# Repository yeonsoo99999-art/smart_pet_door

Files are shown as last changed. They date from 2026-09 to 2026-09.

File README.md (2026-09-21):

# Smart Pet Door — Scratch-to-Open

A cat door that opens for a *request*, not a presence. Instead of a motion or
proximity sensor, a piezo disc listens to the door panel: the cat has to
scratch at a steady rate to "ask", and a leaky-integrator gauge decides when
the request is convincing enough to lift the flap.

One stray knock never opens the door — a single tap lights one pixel of the
gauge and drains away. Only sustained scratching fills the gauge to the
target. Difficulty ("cat personality") is set purely by the decay rate, so a
harder mode asks for *faster* tapping, not harder hits.

<p align="center">
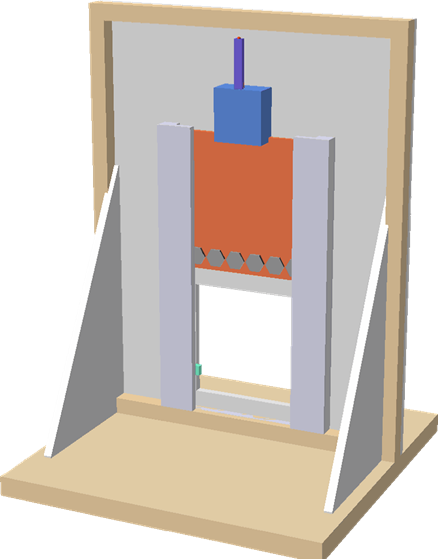
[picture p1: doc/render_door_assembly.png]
Door assembly: servo on top, flap riding in the side channels
  
  &nbsp;&nbsp;
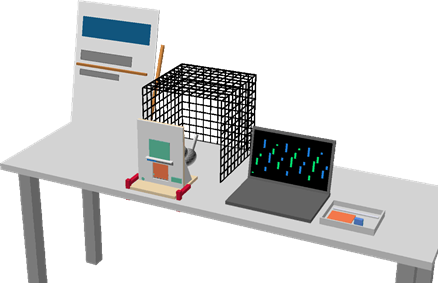
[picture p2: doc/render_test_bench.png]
Test bench: door rig, cat cage and monitoring laptop on a table
  
</p>
<p align="center"><em>Left: door assembly — the SG90 servo lifts the flap through the side channels.
Right: test bench layout with the rig, a cat enclosure and the monitoring laptop.</em></p>

## What's in this repository

| Path | Contents |
|---|---|
| `piezo_servo/` | Arduino sketch: piezo sensing, tap judging, SG90 servo flap drive, MAX7219 8×8 gauge/animations |
| `webview/` | Flask web dashboard — a live 3D digital twin (Three.js) of the door with a scratch simulator, waveform view and request log |
| `doc/` | Laser-cutting DXF files for the MDF enclosure, plus build notes |
| `run.bat` | One-click launcher for the dashboard on Windows |

## Hardware

- Arduino Uno (or compatible)
- Piezo disc → `A0` (signal), GND
- SG90 servo → `D9` (signal), external 5 V supply, common GND
- MAX7219 8×8 LED matrix → `DIN D11`, `CS D10`, `CLK D13`, 5 V, GND
- Laser-cut MDF enclosure (see `doc/README.md` for sheets, parts and assembly)

## Installation

1. **Firmware** — open `piezo_servo/piezo_servo.ino` in the Arduino IDE and
   upload it to the board (115200 baud). On boot it runs a visible self-test:
   full matrix flash, gauge fill, and a servo sweep.

2. **Dashboard** — requires Python 3.10+.

   ```
   pip install -r webview/requirements.txt
   ```

## Usage

Start the dashboard:

```
python webview/app.py --port COM3   # open the serial port at start
python webview/app.py               # or pick the port in the UI
```

Then open http://127.0.0.1:5000. On Windows, `run.bat [COM port]` installs the
dependencies if needed, starts the server and opens the browser.

**No hardware?** Press **Simulate** and drag on the acrylic pad in the 3D view —
pointer speed becomes the piezo peak, and the digital twin runs the exact same
judging logic as the firmware.

Things to try:

- **Cat personality** (Kitten / Adult / Grumpy) changes the decay: minimum tap
  rates of about 1 / 2.5 / 5 taps per second. The setting is sent to the board
  over serial, so the physical door really changes too.
- **Scratch threshold** slider separates table knocks from real scratches.
- **Test servo** sends `o` to the board for a forced open cycle.
- Every successful request is logged with time, mode and peak value
  (`webview/data/requests.csv`).

Serial protocol, difficulty math and sound credits are documented in
`webview/README.md`.

## Author

**Yeonsoo Kang**

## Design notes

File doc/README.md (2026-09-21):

# Laser-cutting DXF — Scratch-to-Open Cat Door

Foam-board prototype panels ported to MDF. Dimensions and mechanics are
unchanged; only the material thicknesses differ.

## Materials

| | Thickness | Used for | Sheet |
|---|---|---|---|
| MDF | **3 mm** | panel, base, braces, channels, servo mount | A, B (600×300) |
| MDF | **2 mm** | flap only | C (200×200) |

**Why two thicknesses.** Channel slot depth = spacer thickness.
A 3 mm spacer gives a 3 mm slot; a 3 mm flap in it has zero clearance and jams.
**A 2 mm flap leaves 1 mm of clearance.** Laser-cut edges are smooth, so 1 mm is enough.

3 mm is the standard laser-cutting thickness: a 40–60 W machine cuts it in one pass.

## Files

```
sheetA_MDF_3T.dxf    600×300 — panel, base #1, servo plate, ribs ×2, LED visor, stopper
sheetB_MDF_3T.dxf    600×300 — braces ×2, base #2, spacers ×2, covers ×2, spares
sheetC_MDF_2T.dxf    200×200 — flap ×2 (one spare)
*_2.7T.dxf           same layout re-fit for 2.7 mm stock
*_tr.dxf / _FIXED    revised nesting variants
```

## Layers

| Layer | Operation |
|---|---|
| `CUT` | cut |
| `ENGRAVE` | engrave (assembly guide lines). Optional, but they make assembly easier |
| `SHEET` | sheet outline. **Do not cut** — layout reference only |

## Parts list

| No. | Part | Qty | Thickness | Notes |
|---|---|---|---|---|
| 01 | Panel 200×260 | 1 | 3T | 70×70 opening, 3 bottom tabs |
| 02 | Base 200×200 | **2** | 3T | **glue 2 layers = 6 mm** so clamps cannot crack it |
| 03 | Brace | 2 | 3T | right triangle 90×160, 4 tabs |
| 04 | Channel spacer 180×10 | 2 | 3T | creates the slot depth |
| 05 | Channel cover 180×22 | 2 | 3T | grips 12 mm of the flap edge |
| 06 | Bottom stopper 90×8 | 1 | 3T | |
| 07 | Servo plate 60×60 | 1 | 3T | 2 slotted SG90 screw holes, Ø14 horn pass-through |
| 08 | Servo rib | 2 | 3T | 18 mm standoff |
| 09 | LED visor 116×20 | 1 | 3T | for direct sunlight outdoors |
| 10 | Flap 90×85 | 2 | **2T** | Ø3 string hole, engraved weight positions |

## Servo mount

The SG90 body does **not** pass through the plate. The flange sits on the front
face and is held by two M2 screws.

- Screw slots: ±13.9 mm from center, **8×2.8 slots** — absorbs hole-spacing
  variation between units
- Ø14 hole: clearance for the horn boss
- The two ribs stand the plate **18 mm off the panel**, so the arm clears the
  channel cover (rear face, Y=79) by 7.5 mm

## Assembly order

```
1. Glue the two base sheets together (6 mm)              cure 2 h
2. Glue channel spacers, then covers, to the panel back  align to engraved lines
3. Insert the flap and free-fall test it                 <- checkpoint
4. Add M8 nuts until the flap weighs 30–40 g (2T MDF is 11 g)
5. Fit the panel's bottom tabs into the base slots
6. Fit both braces into the panel and base slots         check squareness
7. Fit the two servo ribs into the panel slots, seat the servo plate
8. Fasten the servo with two M2 screws; connect arm and string
9. Scratch pad, LEDs, visor, sensors, wiring
```

Tabs press-fit lightly thanks to the kerf (~0.15 mm). If loose, one drop of wood glue.

## Changes from the foam-board version

| | Foam board | MDF |
|---|---|---|
| Panel | 5 mm | **3 mm** |
| Channel spacer | 5 mm | 3 mm |
| Flap | 3 mm foam, 2 g | **2 mm MDF, 11 g** |
| Slot clearance | 2 mm | **1 mm** (smooth cut edges make it enough) |
| Assembly | all glued, aligned by eye | **tab-and-slot self-alignment** |
| Base | 12 mm plywood | two 3T layers = 6 mm |
| Weights | 6–8 M8 nuts | **4 are enough** |

The heavier flap and smoother surfaces **greatly reduce the free-fall failure
risk**, and the torn string holes seen with foam board are gone.

## Cautions

- **MDF is very sensitive to water.** Once wet it swells and is permanently
  damaged. The outdoor-booth rule stands: if it rains, pick it up and retreat.
- Laser-cut edges carry soot. Wipe with a dry cloth before assembly to keep it
  off hands and clothes.
- Cutting 3 mm MDF needs ventilation. Follow your makerspace's rules.

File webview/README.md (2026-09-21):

# Scratch-to-Open · Web View

Flask dashboard that mirrors the cat door as a digital twin. It reads the
`peak,servo` stream from `piezo_servo.ino`, animates the flap, servo arm and
LED gauge, and keeps a request log.

```
pip install -r webview/requirements.txt

python webview/app.py --port COM3   # open the serial port at start
python webview/app.py               # pick the port in the UI, or simulate
```

Then open http://127.0.0.1:5000.

## Serial formats

| Sketch | Line | Handling |
|---|---|---|
| piezo_servo.ino | `peak,servo` | flap follows the reported servo angle |
| catdoor.ino | `peak gauge` | gauge taken from hardware |
| catdoor.ino | `OPEN,<mode>` | open cycle, meow |
| piezo_servo.ino | `mode,i,target,amp` | board confirming difficulty + threshold |
| catdoor.ino | `blocked` | IR beam flag |

`piezo_servo.ino` goes silent once the flap is closed, so a 180° reading older
than 150 ms is treated as closed.

## Simulation

Without hardware, press **Simulate** and drag on the scratch pad. Pointer speed
becomes the piezo peak. A single knock lights one pixel and drains; only a
sustained scratch fills the gauge. Difficulty follows the build book: the
target changes little, the per-window decay is what makes it hard.

Open events are appended to `data/requests.csv`.

## Difficulty

The cat personality sits in the top bar and drives both ends. Picking one sends
`1`, `2` or `3` to the board, which runs the same judge the twin does, so the
physical door really does change. Each tap adds a fixed amount and the gauge
decays continuously, so **what a mode asks for is tapping speed, not force**:

| Mode | Minimum rate | Comfortable rate | Taps to open |
|---|---|---|---|
| Kitten | 1.0 /s | 2 /s | 4 |
| Adult | 2.5 /s | 5 /s | 5 |
| Grumpy | 5.0 /s | 10 /s | 5 |

Below the minimum the gauge can never reach the target, so one stray knock never
opens the door. A sustained scratch hits the ~12.5 taps/s ceiling and opens any
mode. The threshold slider sends `a<n>` to the board; both settings are re-sent
whenever the board reboots, so a brown-out cannot desync the two ends.

## Sound

Each cat personality has its own meow, picked by the active difficulty:

| Mode | File | Character |
|---|---|---|
| Kitten | `meow_kitten.wav` | high soft squeak, ~1960 Hz |
| Adult | `meow_adult.wav` | a cat asking to go out, ~610 Hz |
| Grumpy | `meow_grumpy.wav` | low demanding yowl, ~245 Hz |

Sources and licences are in `static/sound/CREDITS.md`. Browsers block audio until the
page is touched, so the speaker button turns orange with a "click once" tooltip until
then; its first press only unlocks audio, later presses mute and unmute. If the files are
missing, a synthesized meow is used instead.

## Cat coats

The cat behind the door can be black, orange tabby, Siamese, mackerel tabby,
white or calico. Pick it from the selector in the twin card, or pass
`?coat=orange` in the URL. Coats are painted procedurally at load time, so no
image assets are needed.

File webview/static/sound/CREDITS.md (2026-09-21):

# Sound credits

One voice per cat personality. The difficulty mode picks the file, so the pitch
alone tells a visitor which cat they are talking to. All sources are free of
restrictions (CC0 or public domain); no attribution is required and this note
only records provenance.

| Mode | File | Length | Pitch | Source |
|---|---|---|---|---|
| Kitten | `meow_kitten.wav` | 0.81 s | ~1960 Hz, rising | *Cat Purr & Meow* by Kerzoven (`cat_softmew.wav`), CC0 — https://opengameart.org/content/cat-purr-meow |
| Adult | `meow_adult.wav` | 0.62 s | ~610 Hz, asking | *NoTrip* by Heismark, public domain — https://commons.wikimedia.org/wiki/File:NoTrip.ogg |
| Grumpy | `meow_grumpy.wav` | 0.85 s | ~245 Hz, demanding | *Meow of a Siamese cat* by freemaster2, CC0 — https://commons.wikimedia.org/wiki/File:Meow_of_a_Siamese_cat_-_freemaster2.wav |

The adult clip is cut from a recording of a cat asking to be let outside, which is
exactly what this door is about. Only the isolated cat vocalisation is used; the
human speech elsewhere in that recording is not included.

Edits: trimmed to the mew itself, DC removed, peak normalised to −1 dBFS, 5 ms
fade-in and 50 ms fade-out. Format: WAV, mono, 16-bit, 44.1 kHz.

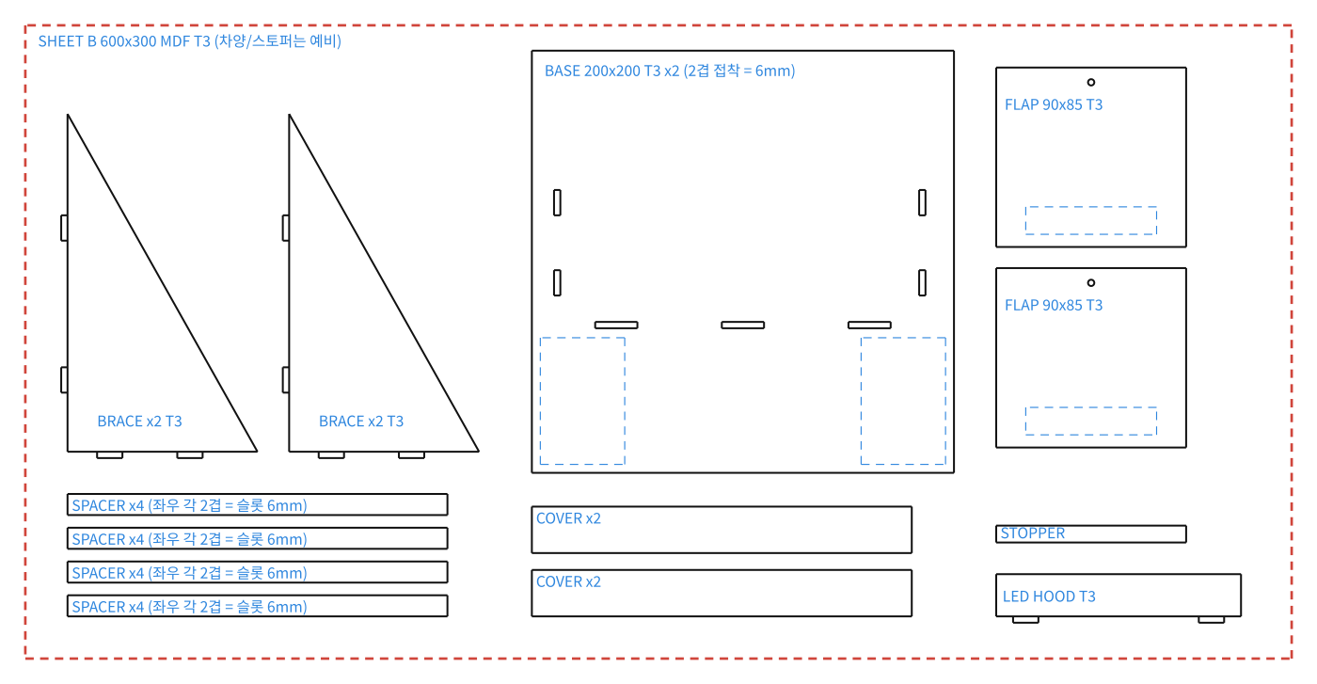
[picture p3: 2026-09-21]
doc/sheetB.png

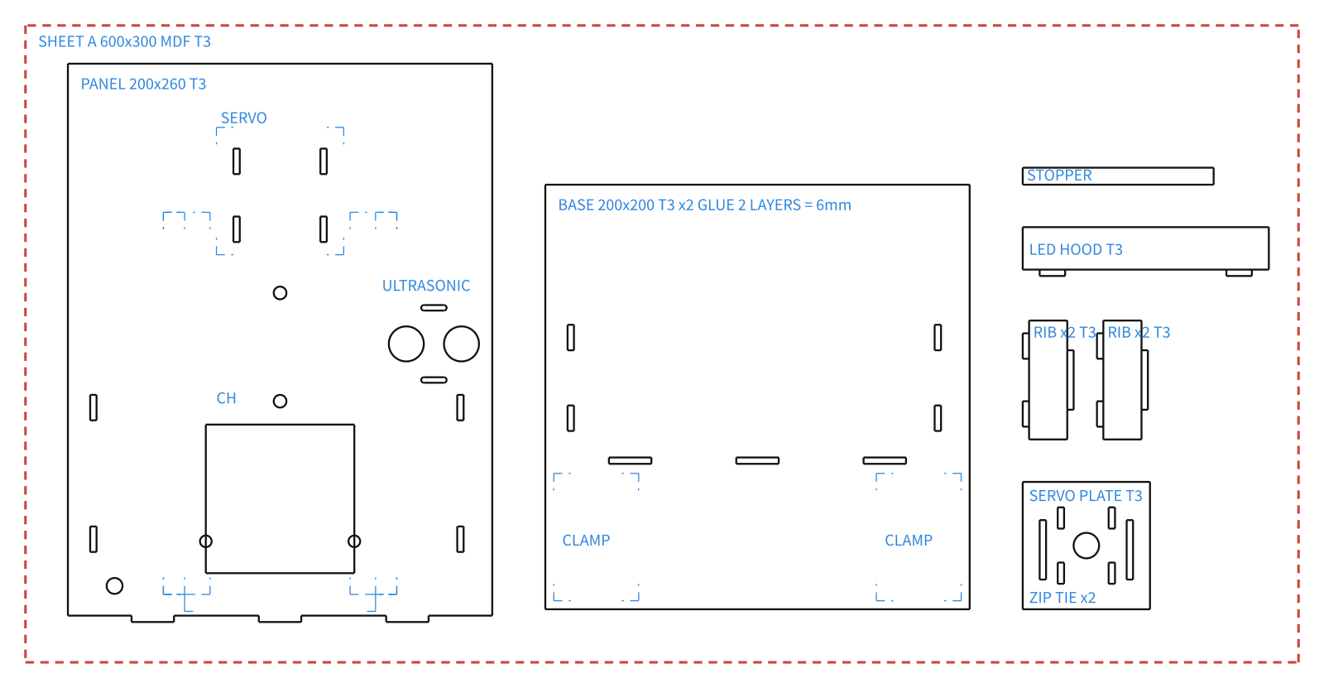
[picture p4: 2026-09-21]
doc/sA.png

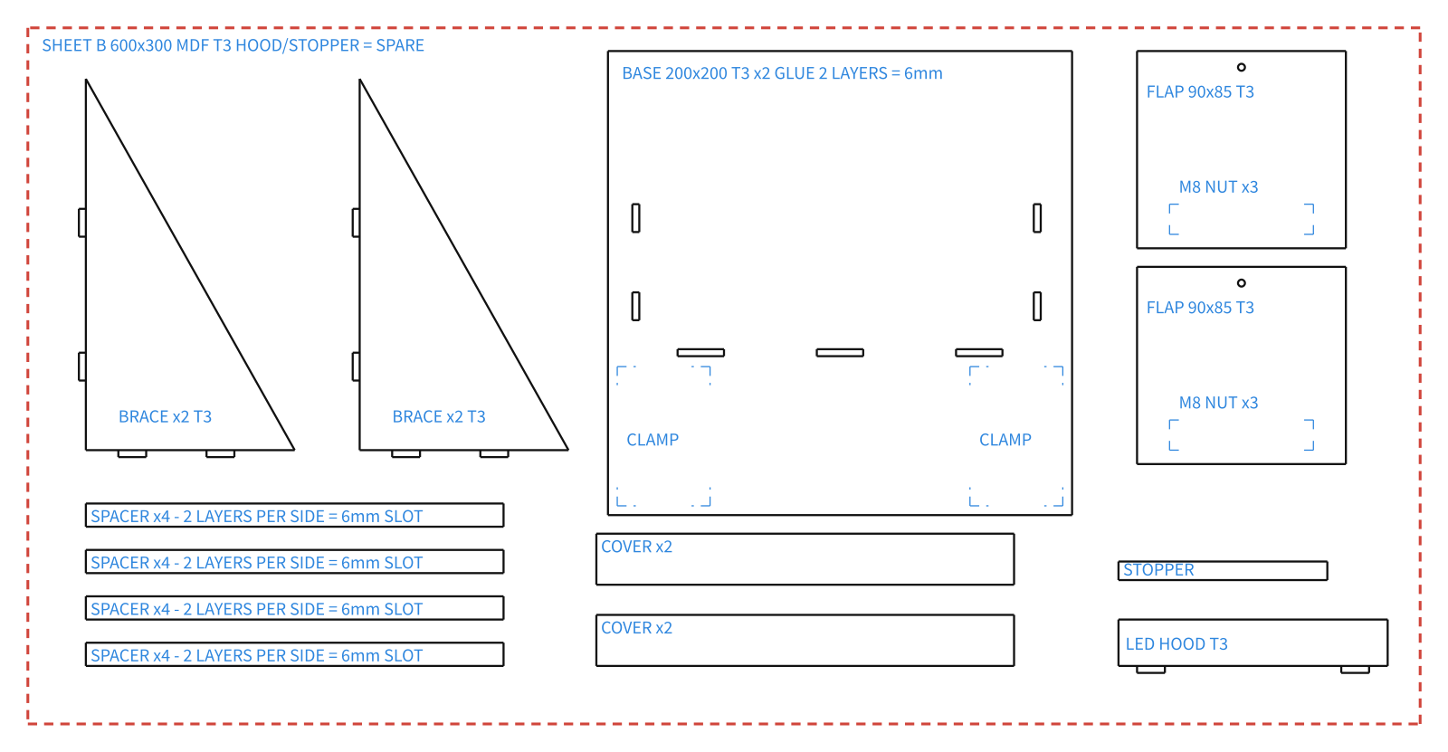
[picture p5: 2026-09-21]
doc/sB.png

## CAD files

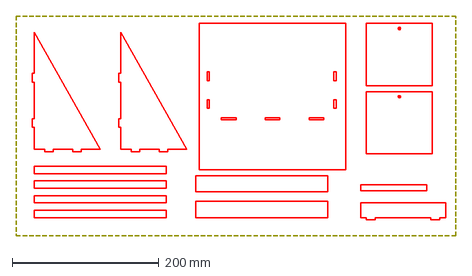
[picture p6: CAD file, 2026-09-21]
doc/sheetB_MDF_3T_tr.dxf
600.0 x 300.0 mm

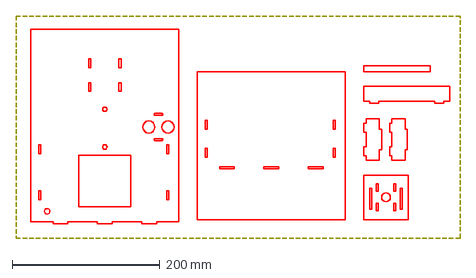
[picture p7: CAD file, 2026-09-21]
doc/sheetA_MDF_3T_tr.dxf
600.0 x 300.0 mm

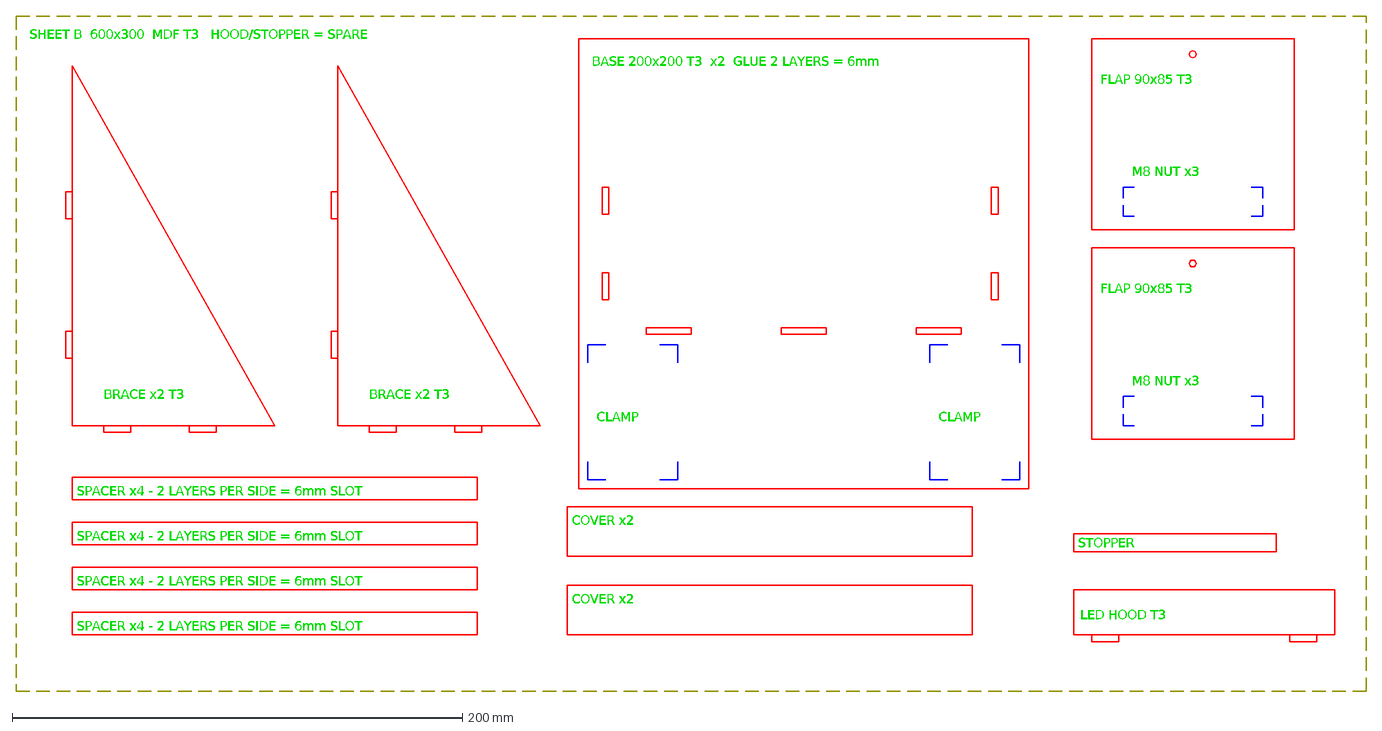
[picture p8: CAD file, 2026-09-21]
doc/sheetB_MDF_3T.dxf
SPACER x4 - 2 LAYERS PER SIDE = 6mm SLOT
COVER x2
BRACE x2 T3
CLAMP
BASE 200x200 T3 x2 GLUE 2 LAYERS = 6mm
M8 NUT x3
FLAP 90x85 T3
LED HOOD T3
STOPPER
SHEET B 600x300 MDF T3 HOOD/STOPPER = SPARE

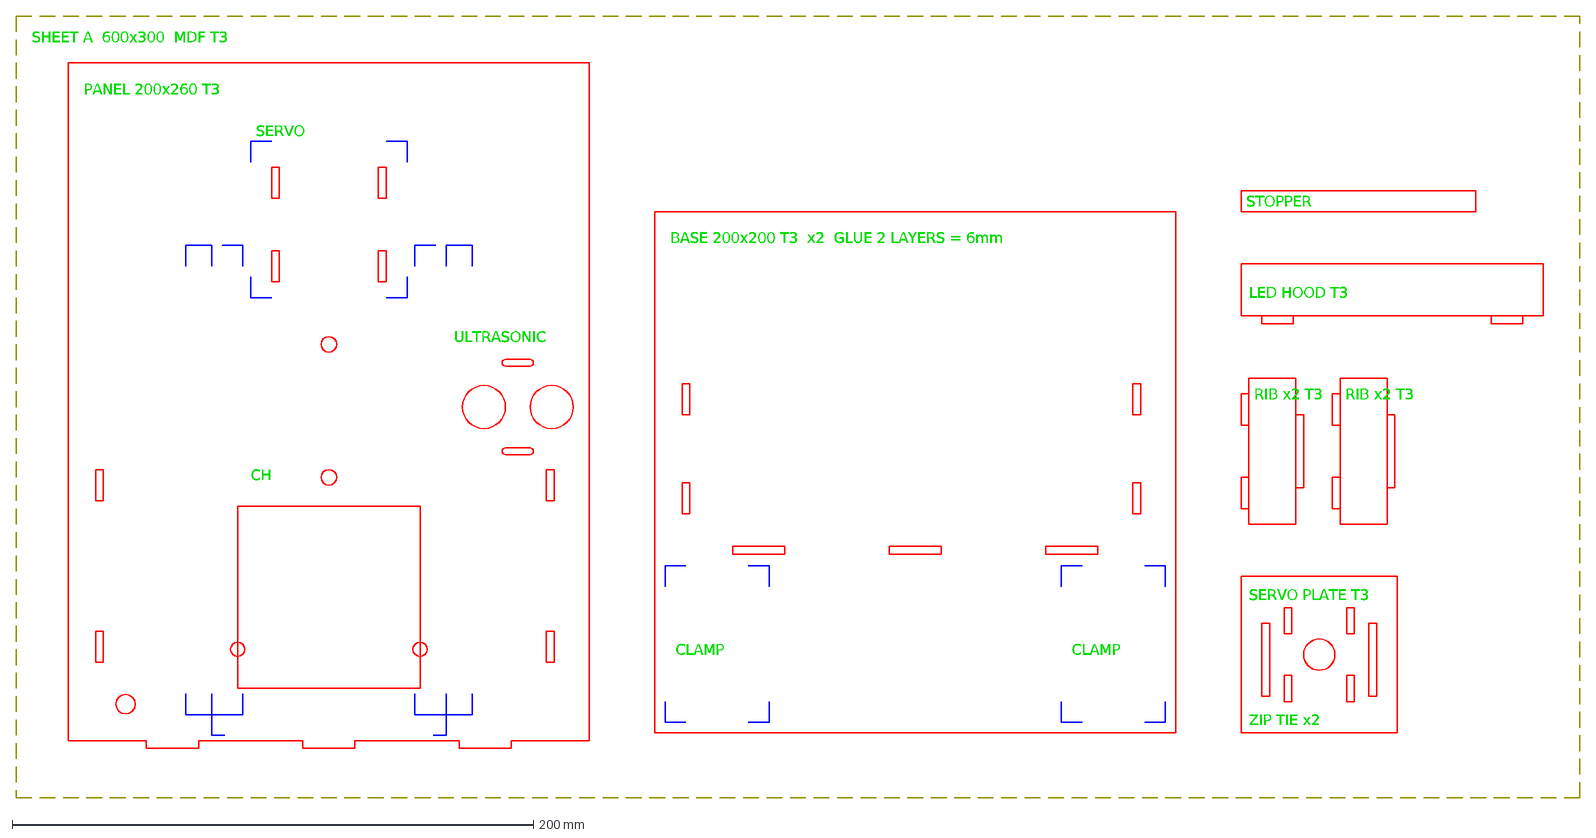
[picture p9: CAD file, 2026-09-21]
doc/sheetA_MDF_3T.dxf
SERVO
CH
PANEL 200x260 T3
ULTRASONIC
CLAMP
BASE 200x200 T3 x2 GLUE 2 LAYERS = 6mm
SERVO PLATE T3
ZIP TIE x2
RIB x2 T3
LED HOOD T3
STOPPER
SHEET A 600x300 MDF T3

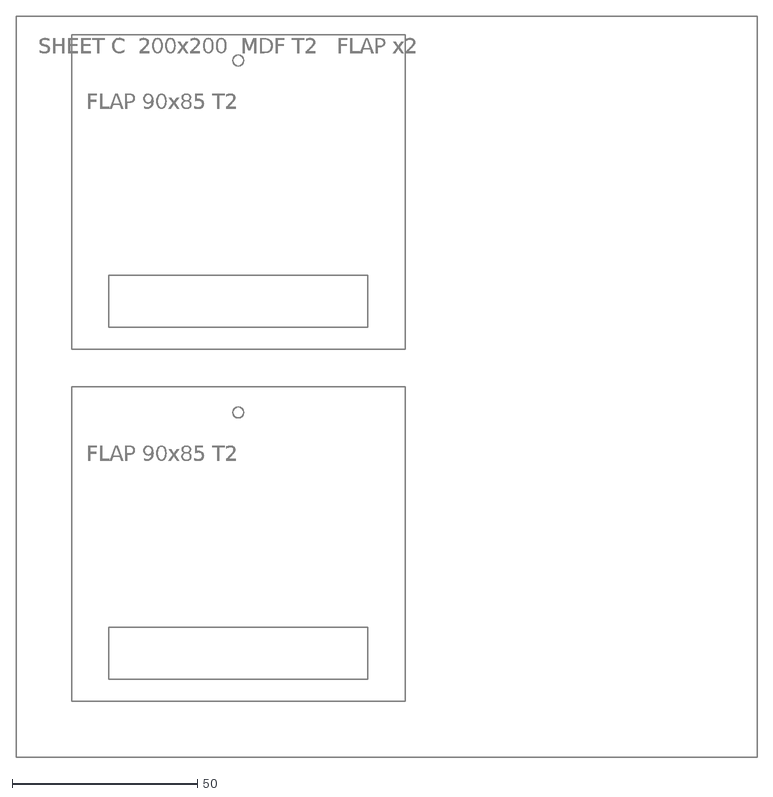
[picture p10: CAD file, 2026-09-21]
doc/sheetC_MDF_2T.dxf
FLAP 90x85 T2
SHEET C 200x200 MDF T2 FLAP x2

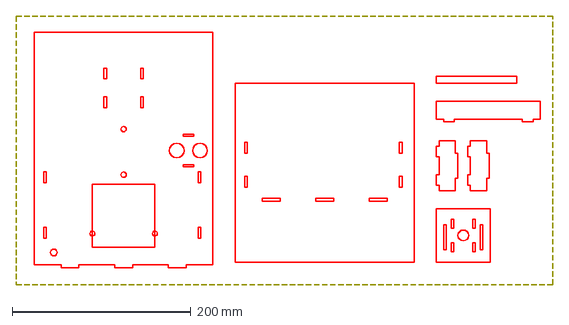
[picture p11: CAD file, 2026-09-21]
doc/sheetA_MDF_3T_FIXED.dxf
600.0 x 300.0 mm

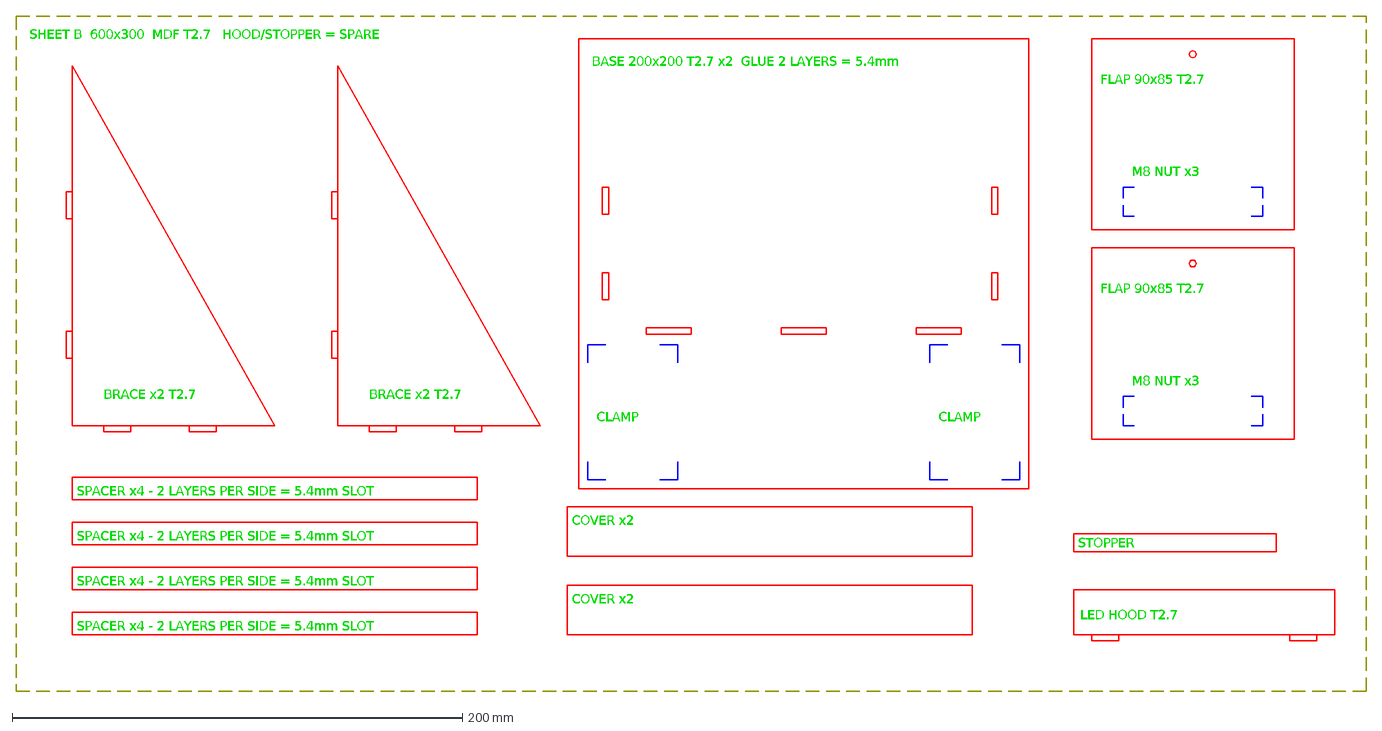
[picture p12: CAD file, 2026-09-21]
doc/sheetB_MDF_2.7T.dxf
SPACER x4 - 2 LAYERS PER SIDE = 5.4mm SLOT
COVER x2
BRACE x2 T2.7
CLAMP
BASE 200x200 T2.7 x2 GLUE 2 LAYERS = 5.4mm
M8 NUT x3
FLAP 90x85 T2.7
LED HOOD T2.7
STOPPER
SHEET B 600x300 MDF T2.7 HOOD/STOPPER = SPARE

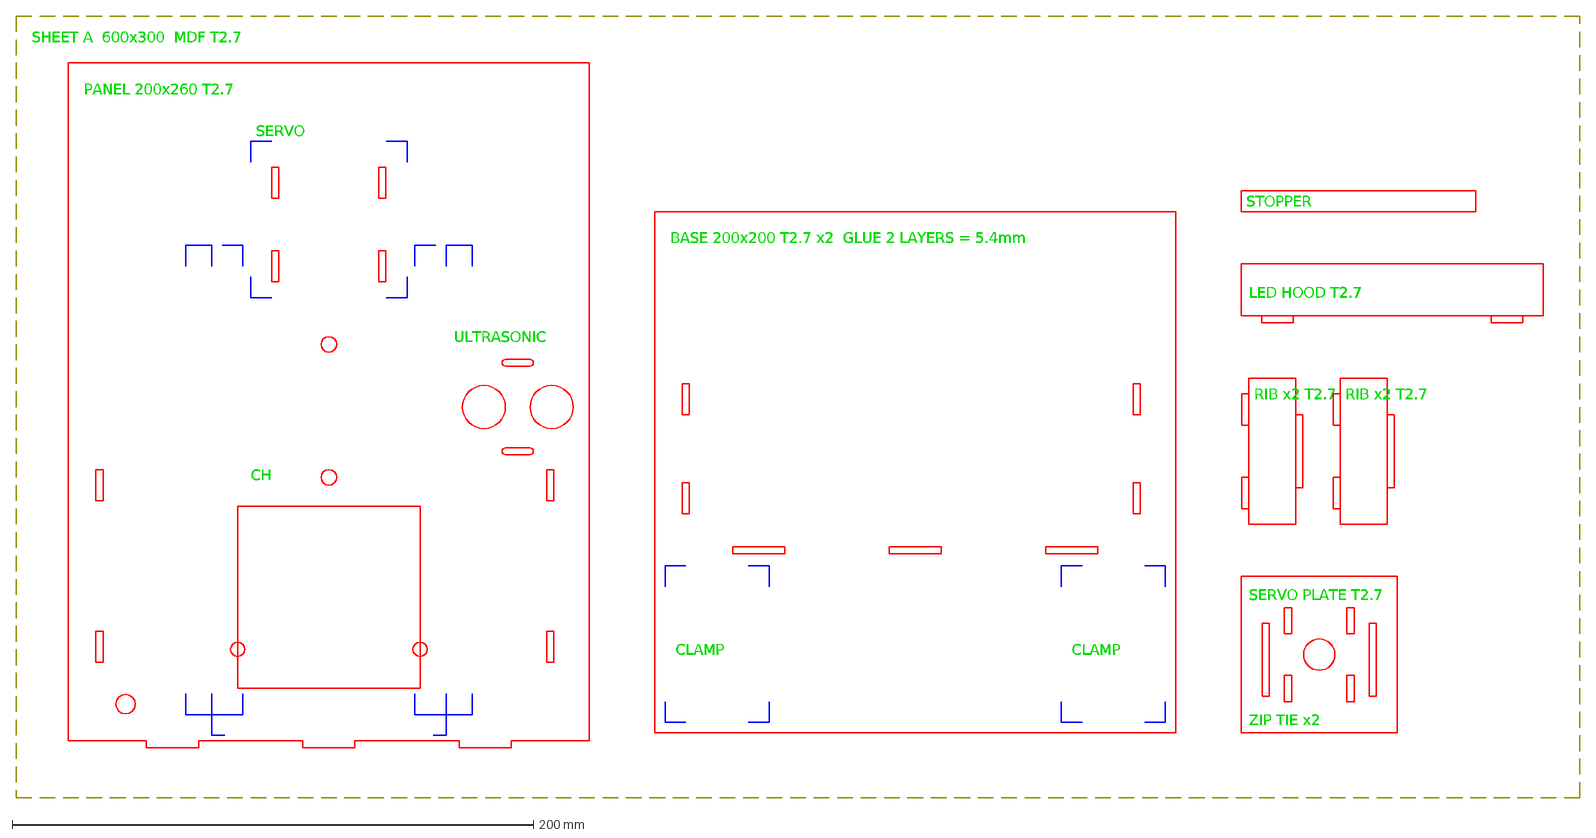
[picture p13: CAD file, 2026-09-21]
doc/sheetA_MDF_2.7T.dxf
SERVO
CH
PANEL 200x260 T2.7
ULTRASONIC
CLAMP
BASE 200x200 T2.7 x2 GLUE 2 LAYERS = 5.4mm
SERVO PLATE T2.7
ZIP TIE x2
RIB x2 T2.7
LED HOOD T2.7
STOPPER
SHEET A 600x300 MDF T2.7

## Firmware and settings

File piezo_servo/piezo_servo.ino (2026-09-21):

// Scratch-to-Open test rig: piezo -> leaky-integrator gauge -> servo -> MAX7219 meter.
//
// Each tap raises the gauge by TAP_RISE, and every sample window subtracts a decay.
// What matters is therefore not how hard you hit, but how many taps per second.
// Difficulty is made by the decay, not the target (build-book rule): a larger
// decay means you must tap faster.
//
// Wiring: piezo signal -> A0
//         servo signal -> D9
//         servo VCC/GND -> external 5V; tie GND common with the Arduino.
//         MAX7219 8x8 matrix: DIN -> D11, CS -> D10, CLK -> D13, VCC 5V, GND
//
// The matrix is the persuasion gauge. While the door is closed it fills in
// proportion to the target (8 columns = open); while the door moves it shows the
// flap lifting; while open it shows a cat face.
//
// Output: peak,servo,gauge  (CSV) at 115200
// Input:  'o'    force one open cycle (servo self-test from the laptop)
//         'm'    light the whole matrix for 0.6 s (wiring check)
//         '1'    kitten   '2' adult   '3' grumpy
//         'a123' set the scratch threshold (SCRATCH_AMP) to 123; newline after digits.

#include <Servo.h>

const int PIN_PIEZO = A0;
const int PIN_SERVO = 9;
const int PIN_MX_DIN = 11;
const int PIN_MX_CS  = 10;
const int PIN_MX_CLK = 13;

const byte MX_INTENSITY = 8;        // 0..15; outdoor booth may want 12+
const bool MX_FLIP_X = false;       // flip if the bar fills from the wrong side
const bool MX_FLIP_Y = false;       // flip if the flap animation runs upside down

const int NOISE_FLOOR = 25;  // measure with no vibration and set accordingly

const int ANG_CLOSED = 0;
const int ANG_OPEN   = 80;              // sets the flap lift for the R45 arm
const unsigned long HOLD_MS     = 3000; // how long the door stays open
const unsigned long COOLDOWN_MS = 1000; // delay before reacting again after closing
const int SWEEP_MS  = 500;              // 0 -> ANG_OPEN travel time
const bool REST_DETACH = true;          // stop pulses when closed: no hum, no idle current

// Pulse limits. Cheap SG90 clones stall and overheat when driven to the default
// 544/2400 us extremes, so keep a margin and never command a mechanical stop.
const int PULSE_MIN_US = 600;
const int PULSE_MAX_US = 2300;

// ---- judging: tap-driven leaky integrator ------------------------------
// The window is fixed by sample count, not time. About 21 ms on an Uno.
const int SAMPLES = 200;
const int WINDOW_MS = 21;           // measured length of the window above
const int GAUGE_MAX = 200;
int scratchAmp = 80;                // a peak above this counts as one tap

// One tap = TAP_RISE. The refractory time stops a single strike counting twice;
// a continuous scratch lands one tap per refractory period, capping the tap rate
// at about 12.5 taps/s.
const int TAP_RISE = 40;
const int TAP_REFRACTORY_MS = 80;
const int DIFF_TARGET = 100;        // shared by all three modes; only decay differs

// Decay per window. The larger this is, the faster you must tap for the gauge to win.
// Minimum rate (taps/s) = decay x (1000/21) / TAP_RISE  ->  about 1 / 2.5 / 5 taps/s.
// Tapping at twice that rate opens any mode in about 5 taps.
const float DIFF_DECAY[3] = { 0.8, 2.1, 4.2 };
int diff = 1;                       // 0 kitten, 1 adult, 2 grumpy
float gauge = 0;
unsigned long lastTap = 0;

// Non-blocking sweep: the servo advances a few degrees per sample window, so the
// piezo keeps streaming while the flap moves.
const int STEP_DEG = max(1, (int)((long)(ANG_OPEN - ANG_CLOSED) * WINDOW_MS / SWEEP_MS));

Servo servo;

enum State { CLOSED, OPENING, OPEN, CLOSING };
State state = CLOSED;
int angle  = ANG_CLOSED;        // last angle written
int target = ANG_CLOSED;
unsigned long stateSince = 0;   // time of the last state transition

// ---- MAX7219, bit-banged (no library) ---------------------------------

void mxSend(byte reg, byte data) {
  digitalWrite(PIN_MX_CS, LOW);
  shiftOut(PIN_MX_DIN, PIN_MX_CLK, MSBFIRST, reg);
  shiftOut(PIN_MX_DIN, PIN_MX_CLK, MSBFIRST, data);
  digitalWrite(PIN_MX_CS, HIGH);
}

byte flipBits(byte b) {
  byte r = 0;
  for (int i = 0; i < 8; i++) if (b & (1 << i)) r |= 0x80 >> i;
  return r;
}

// rows[0] is the top row, bit 7 the leftmost column. Unchanged frames are not resent.
byte mxShown[8];
void mxFrame(const byte rows[8]) {
  if (memcmp(rows, mxShown, 8) == 0) return;
  memcpy(mxShown, rows, 8);
  for (int i = 0; i < 8; i++) {
    byte row = rows[MX_FLIP_Y ? 7 - i : i];
    mxSend(i + 1, MX_FLIP_X ? flipBits(row) : row);
  }
}

void mxInit() {
  pinMode(PIN_MX_DIN, OUTPUT);
  pinMode(PIN_MX_CS, OUTPUT);
  pinMode(PIN_MX_CLK, OUTPUT);
  digitalWrite(PIN_MX_CS, HIGH);
  mxSend(0x0F, 0);            // display test off
  mxSend(0x09, 0);            // no BCD decode
  mxSend(0x0B, 7);            // scan all 8 digits
  mxSend(0x0A, MX_INTENSITY);
  mxSend(0x0C, 1);            // normal operation
  memset(mxShown, 0xFF, 8);
  const byte blank[8] = {0, 0, 0, 0, 0, 0, 0, 0};
  mxFrame(blank);
}

void mxTest() {
  mxSend(0x0F, 1);
  delay(600);
  mxSend(0x0F, 0);
}

const byte CAT_FACE[8] = {
  0b10000001,
  0b11000011,
  0b11111111,
  0b10111101,
  0b11111111,
  0b11100111,
  0b01111110,
  0b00111100,
};

// closed door at rest: frame outline with the flap inside
const byte DOOR_CLOSED[8] = {
  0b11111111,
  0b10000001,
  0b10111101,
  0b10111101,
  0b10111101,
  0b10111101,
  0b10000001,
  0b11111111,
};

// gauge: columns fill from the left, all rows lit; the door glyph shows while empty
void drawMeter(float level) {
  int cols = constrain((int)(level + 0.5), 0, 8);
  if (cols == 0) { mxFrame(DOOR_CLOSED); return; }
  byte row = (byte)(0xFF << (8 - cols));
  byte rows[8];
  for (int i = 0; i < 8; i++) rows[i] = row;
  mxFrame(rows);
}

// door frame with the flap drawn from the top; the gap grows from the bottom as it lifts
void drawFlap(int deg) {
  int gap = constrain((long)deg * 6 / ANG_OPEN, 0, 6);   // rows revealed inside the frame
  byte rows[8];
  rows[0] = 0xFF;
  rows[7] = 0xFF;
  for (int i = 1; i < 7; i++) rows[i] = (i > 6 - gap) ? 0x81 : 0xFF;
  mxFrame(rows);
}

void drawFace(bool blink) {
  byte rows[8];
  memcpy(rows, CAT_FACE, 8);
  if (blink) rows[3] = 0b11111111;
  mxFrame(rows);
}

// ---- serial commands ---------------------------------------------------

void reportMode() {
  Serial.print("mode,");
  Serial.print(diff);
  Serial.print(',');
  Serial.print(DIFF_TARGET);
  Serial.print(',');
  Serial.println(scratchAmp);
}

// Returns true if a forced open was requested.
bool readCommands() {
  static char argCmd = 0;       // command still collecting digits
  static int  argVal = -1;
  bool force = false;

  while (Serial.available()) {
    char c = Serial.read();

    if (argCmd && c >= '0' && c <= '9') {         // digits belong to the pending command
      argVal = (argVal < 0 ? 0 : argVal) * 10 + (c - '0');
      continue;
    }
    if (argCmd) {                                  // any other byte ends it
      if (argCmd == 'a' && argVal > 0) { scratchAmp = constrain(argVal, 10, 1023); reportMode(); }
      argCmd = 0;
      argVal = -1;
    }

    if (c == 'a' || c == 'A') { argCmd = 'a'; continue; }
    if (c == 'o' || c == 'O') force = true;
    if (c == 'm' || c == 'M') mxTest();
    if (c >= '1' && c <= '3') { diff = c - '1'; gauge = 0; reportMode(); }
  }
  return force;
}

void setup() {
  Serial.begin(115200);
  Serial.println("peak,servo,gauge");
  servo.attach(PIN_SERVO, PULSE_MIN_US, PULSE_MAX_US);
  mxInit();
  mxTest();                                                   // every LED on: wiring check
  for (int c = 1; c <= 8; c++) { drawMeter(c); delay(60); }   // then the gauge fills once

  // Boot self-test: a visible sweep proves power and signal before any scratch.
  servo.write(ANG_CLOSED);
  delay(300);
  servo.write(ANG_OPEN / 2);
  delay(400);
  servo.write(ANG_CLOSED);
  delay(400);
  if (REST_DETACH) servo.detach();
  reportMode();
  stateSince = millis();
}

void loop() {
  // Take the peak amplitude over a fixed number of samples (one window).
  int peak = 0;
  for (int i = 0; i < SAMPLES; i++) {
    int v = analogRead(PIN_PIEZO);
    if (v > peak) peak = v;
  }

  bool force = readCommands();
  unsigned long now = millis();

  // Tap judgement. Ringing inside the refractory time counts as the same strike.
  bool tapped = false;
  if (peak >= scratchAmp && now - lastTap >= (unsigned long)TAP_REFRACTORY_MS) {
    lastTap = now;
    tapped = true;
  }

  // Rise vs decay. The gauge only accumulates while the door is closed.
  if (state == CLOSED) {
    gauge += (tapped ? TAP_RISE : 0) - DIFF_DECAY[diff];
    gauge = constrain(gauge, 0, (float)GAUGE_MAX);
  }

  switch (state) {
    case CLOSED:
      if ((gauge >= DIFF_TARGET && now - stateSince >= COOLDOWN_MS) || force) {
        if (!servo.attached()) servo.attach(PIN_SERVO, PULSE_MIN_US, PULSE_MAX_US);
        target = ANG_OPEN;
        state = OPENING;
        stateSince = now;
      }
      break;
    case OPENING:
      if (angle == target) { state = OPEN; stateSince = now; }
      break;
    case OPEN:
      if (now - stateSince >= HOLD_MS) { target = ANG_CLOSED; state = CLOSING; stateSince = now; }
      break;
    case CLOSING:
      if (angle == target) {
        state = CLOSED;
        stateSince = now;
        gauge = 0;
        if (REST_DETACH) servo.detach();
      }
      break;
  }

  // one step toward the target per window
  if (angle < target) {
    angle = min(target, angle + STEP_DEG);
    servo.write(angle);
  } else if (angle > target) {
    angle = max(target, angle - STEP_DEG);
    servo.write(angle);
  }

  // matrix
  switch (state) {
    case CLOSED:
      drawMeter(gauge * 8.0f / DIFF_TARGET);
      break;
    case OPENING:
    case CLOSING:
      drawFlap(angle);
      break;
    case OPEN:
      drawFace(((now - stateSince) / 150) % 12 == 11);   // occasional blink
      break;
  }

  if (peak > NOISE_FLOOR || gauge > 0 || state != CLOSED) {
    Serial.print(peak);
    Serial.print(',');
    Serial.print(angle);
    Serial.print(',');
    Serial.println((int)gauge);
  }
}

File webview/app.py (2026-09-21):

import argparse
import json
import os
import time

from flask import Flask, Response, jsonify, render_template, request

from serial_link import SerialLink, available_ports
from twin import Twin

BASE = os.path.dirname(os.path.abspath(__file__))
LOG_PATH = os.path.join(BASE, "data", "requests.csv")
os.makedirs(os.path.dirname(LOG_PATH), exist_ok=True)

app = Flask(__name__)
twin = Twin(log_path=LOG_PATH)
link = SerialLink(twin)


@app.route("/")
def index():
    return render_template("index.html")


@app.get("/api/state")
def state():
    return jsonify(twin.snapshot())


@app.get("/api/stream")
def stream():
    def gen():
        while True:
            yield f"data: {json.dumps(twin.snapshot())}\n\n"
            time.sleep(0.05)
    return Response(gen(), mimetype="text/event-stream",
                    headers={"Cache-Control": "no-cache", "X-Accel-Buffering": "no"})


@app.get("/api/history")
def history():
    return jsonify(twin.recent_history())


@app.get("/api/events")
def events():
    return jsonify(twin.recent_events())


@app.delete("/api/events")
def clear_events():
    twin.reset_count()
    return jsonify(ok=True)


@app.get("/api/ports")
def ports():
    return jsonify(ports=available_ports(), connected=link.connected,
                   port=twin.port if link.connected else None, error=link.error)


@app.post("/api/connect")
def connect():
    body = request.get_json(silent=True) or {}
    port = body.get("port")
    if not port:
        return jsonify(ok=False, error="port required"), 400
    try:
        link.open(port, int(body.get("baud", 115200)))
    except Exception as e:  # pyserial raises several types here
        return jsonify(ok=False, error=str(e)), 400
    return jsonify(ok=True, port=port)


@app.post("/api/disconnect")
def disconnect():
    link.close()
    return jsonify(ok=True)


@app.post("/api/sim")
def sim():
    body = request.get_json(silent=True) or {}
    if link.connected:
        return jsonify(ok=False, error="serial active"), 409
    if body.get("enable", True):
        twin.set_source("sim")
    else:
        twin.set_source("none")
    return jsonify(ok=True)


@app.post("/api/test_open")
def test_open():
    if link.connected:
        ok = link.write(b"o")
        return jsonify(ok=ok, error=link.error if not ok else None), (200 if ok else 500)
    if twin.source == "sim":
        twin.force_open()
        return jsonify(ok=True)
    return jsonify(ok=False, error="not connected"), 409


@app.post("/api/scratch")
def scratch():
    body = request.get_json(silent=True) or {}
    if twin.source != "sim":
        return jsonify(ok=False, error="sim mode off"), 409
    peak = max(0, min(1023, int(body.get("peak", 0))))
    twin.feed(peak)
    return jsonify(ok=True)


@app.post("/api/settings")
def settings():
    body = request.get_json(silent=True) or {}
    twin.update_settings(body)
    # The board runs the same leaky integrator, so keep its mode and threshold in step.
    if link.connected:
        if "difficulty" in body:
            link.write(twin.difficulty_code())
        if "scratch_amp" in body:
            link.write(twin.amp_code())
    return jsonify(twin.snapshot())


def main():
    p = argparse.ArgumentParser()
    p.add_argument("--port", help="serial port to open at start (e.g. COM3)")
    p.add_argument("--baud", type=int, default=115200)
    p.add_argument("--host", default="127.0.0.1")
    p.add_argument("--http", type=int, default=5000)
    args = p.parse_args()

    if args.port:
        try:
            link.open(args.port, args.baud)
        except Exception as e:
            print(f"serial: {e}")

    app.run(host=args.host, port=args.http, threaded=True, debug=False)


if __name__ == "__main__":
    main()

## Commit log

2026-09-21 Add Scratch-to-Open firmware, digital-twin dashboard and laser-cut design files
    [sheetA_MDF_2.7T.dxf, sheetA_MDF_3T.dxf, sheetA_MDF_3T_FIXED.dxf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]
2026-09-21 Add 3D renders of the door assembly and test bench to the README
